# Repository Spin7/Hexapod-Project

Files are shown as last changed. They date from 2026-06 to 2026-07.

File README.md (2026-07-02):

# Hexapod Project

<p align="center">
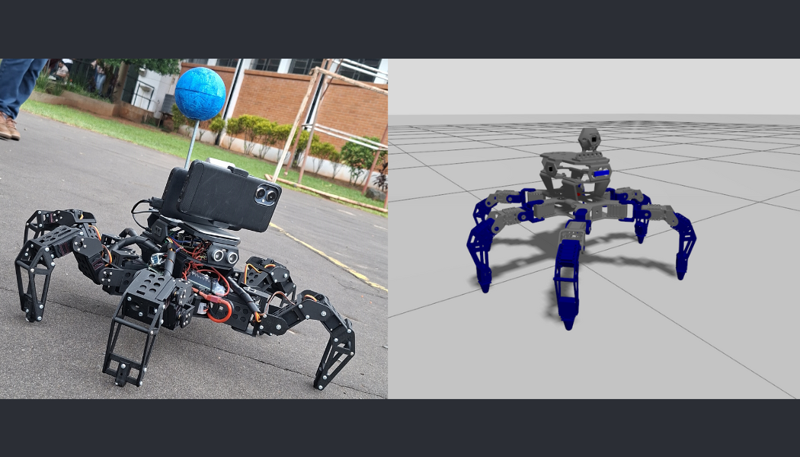
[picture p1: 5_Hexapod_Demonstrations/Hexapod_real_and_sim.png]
Hexapod — Real robot and Gazebo simulation
  
</p>

<p align="center">
  <em>Left: Physical hexapod robot in action · Right: Gazebo simulation counterpart</em>
</p>

<p align="center">
  
  
  
  
  
  
</p>

---

## Overview

This repository contains the complete development of a **6-legged autonomous robot (hexapod)** — from mechanical 3D design and embedded firmware, to a full ROS2 software stack running in both **Gazebo simulation** and on the **physical robot**.

The core philosophy is **dual-execution**: one shared intelligence layer drives two physical realities. The same high-level behaviors — autonomous navigation, vision-based following, swarm coordination, hand-gesture interaction — run identically on the simulator and the real hardware. The only difference is the actuation layer.

```
Behavior / Navigation / Social Logic
              ↓
      cmd_robot (std_msgs/String)
              ↓
  ┌───────────────────────────┐
  │ SIMULATION                │     │ REAL ROBOT                │
  │  gz_hexapod_low_level     │     │  dds_cmd_talker           │
  │    → joint trajectories   │     │    → serial → Arduino     │
  └───────────────────────────┘     └───────────────────────────┘
```

---

## Hardware Platform

| Component | Details |
|---|---|
| 🖥️ **PC** | ASUS TUF Gaming F15 — NVIDIA RTX 3060 · Ubuntu 24.04 LTS |
| 🍓 **Raspberry Pi** | Raspberry Pi 4 (4 GB RAM) · Ubuntu 24.04 LTS |
| 🔌 **Microcontroller** | Arduino Mega (18 servo motors — 3 DOF × 6 legs) |
| 📱 **Smartphone** | Google Pixel 7 (camera + IMU sensors via SensorServer) |
| 🦿 **Mechanics** | Custom 3D-printed chassis · SolidWorks design |
| 📡 **Sensors** | HC-SR04 ultrasonic · IMU · GPS (via smartphone) · IR proximity |

---

## Repository Structure

```
Hexapod Project/
├── 1_ROS2_Gazebo_Project/       # Full ROS2 package (simulation + real robot)
├── 2_Arduino_Code/              # Arduino Mega firmware (IK + gait + serial control)
├── 3_3D_Design/                 # SolidWorks assembly + printable STL files
├── 4_SensorServer_App/          # Android app APK for phone sensor streaming
├── 5_Hexapod_Demonstrations/    # Video demos and side-by-side images
└── 6_Multimedia/                # Photos and media assets
```

---

## Modules

### 1 — ROS2 Gazebo Project

> **Path:** [`1_ROS2_Gazebo_Project/`](1_ROS2_Gazebo_Project/)  
> **See:** [`1_ROS2_Gazebo_Project/README.md`](1_ROS2_Gazebo_Project/README.md)

The brain of the system. A single colcon package (`hexapod_pkg`) that runs on both the PC (simulation and high-level control) and the Raspberry Pi (hardware sensor reading).

**Key node groups:**

| Module | Role |
|---|---|
| `dds_nodes` | DDS bridge — PC ↔ Arduino serial communication |
| `navigation_nodes` | GPS-based autonomous navigation + obstacle avoidance |
| `image_recognition_nodes` | YOLO object detection + MediaPipe hand tracking |
| `localization_and_orientation_nodes` | GPS, IMU heading, dead-reckoning fusion |
| `sensors_interfaces_nodes` | Ultrasonic sensor processing |
| `social_robot_nodes` | Hand-gesture-based human–robot interaction |
| `auto_balance_nodes` | IMU-driven postural correction (roll/pitch) |
| `gazebo_nodes` | Simulation-specific low-level joint control |
| `read_sensors_nodes` | Hardware sensor readers (Raspberry Pi side) |
| `teleop_nodes` | Keyboard / manual override |

**Operation modes:**

| Mode | Description |
|---|---|
| 🎯 **Follower** | YOLO-based visual target tracking and pursuit |
| 🗺️ **Navigation to Target** | GPS + heading + obstacle avoidance autonomous travel |
| 🐝 **Swarm Follower** | Leader-following with simplified collective rules |
| 🖐️ **Social Robot** | Hand gesture recognition (ROCK / VICTORY / AL_PELO) → motion commands |
| 🕹️ **Teleop** | Direct keyboard control for debugging and calibration |

---

### 2 — Arduino Code

> **Path:** [`2_Arduino_Code/`](2_Arduino_Code/)

Arduino Mega firmware written in C++. Receives high-level movement commands over serial from the Raspberry Pi (via ROS2 DDS bridge) and translates them into real-time servo trajectories using **Inverse Kinematics (IK)**.

**Key features:**
- 18 servo motors controlled at **50 Hz** (20 ms frame time)
- 3 DOF per leg: **Coxa · Femur · Tibia** — lengths: 51 mm / 65 mm / 121 mm
- IK-based foot placement for forward, backward, lateral, and rotational gaits
- Battery voltage monitoring (12V analog input)
- Includes a PDF wiring and setup guide ([`Arduino_Instructions.pdf`](2_Arduino_Code/Arduino_Instructions.pdf))

---

### 3 — 3D Design

> **Path:** [`3_3D_Design/`](3_3D_Design/)

Full mechanical design created in **SolidWorks**. The assembly (`Ensamblaje.SLDASM`) covers the entire robot structure with all sub-components modeled and parametrized.

**Printable STL parts include:**

| Part | Description |
|---|---|
| `Body_Top_Plate.stl` / `Body_Bottom_Plate.stl` | Main chassis plates |
| `Body_Riser.stl` | Chassis elevation spacers |
| `Femur_Bracket.stl` / `Femur_Bracket_End_Cap.stl` | Mid-leg structural brackets |
| `Tibia_Bracket.stl` / `Tibia_Side_1.stl` / `Tibia_Side_2.stl` | Lower leg components |
| `Tibia_Foot_Bumper.stl` / `Tibia_Foot_Plate.stl` | Foot contact surface |
| `Servo_Mount.stl` / `Servo_Bearing_Center.stl` | Servo attachment fixtures |
| `Wire_Guide.stl` | Cable management |
| `Receiver_Holder.stl` / `SBEC_Holder.stl` | Electronics holders |
| `Soporte/` | Mounting brackets for Raspberry Pi 5 and Pi Camera |

Additional sub-assemblies include custom mounts for the **HC-SR04** ultrasonic sensors and the **JS40F** servo joints. A full parts list is available at [`stl files/Robot/Parts-List.pdf`](3_3D_Design/Hexapod%203D%20model/stl%20files/Robot/Parts-List.pdf).

---

### 4 — SensorServer App

> **Path:** [`4_SensorServer_App/`](4_SensorServer_App/)  
> **GitHub:** [github.com/UmerCodez/SensorServer](https://github.com/UmerCodez/SensorServer)

An Android application that streams all smartphone sensors (GPS, accelerometer, gyroscope, magnetometer) over **WebSocket** to the ROS2 network. This turns a regular smartphone into a powerful sensor hub for the hexapod, providing:

- **GPS** — global position for autonomous navigation
- **IMU** — accelerometer + gyroscope + magnetometer for heading estimation
- **Camera** — phone camera streamed via **IriunWebCam** to the PC

The APK is included in this folder for direct installation.

---

### 5 — Hexapod Demonstrations

> **Path:** [`5_Hexapod_Demonstrations/`](5_Hexapod_Demonstrations/)  
> **See:** [`5_Hexapod_Demonstrations/README.md`](5_Hexapod_Demonstrations/README.md)

Video recordings of all operation modes on both the real robot and the simulation. Organized into two sub-folders:

<p align="center">
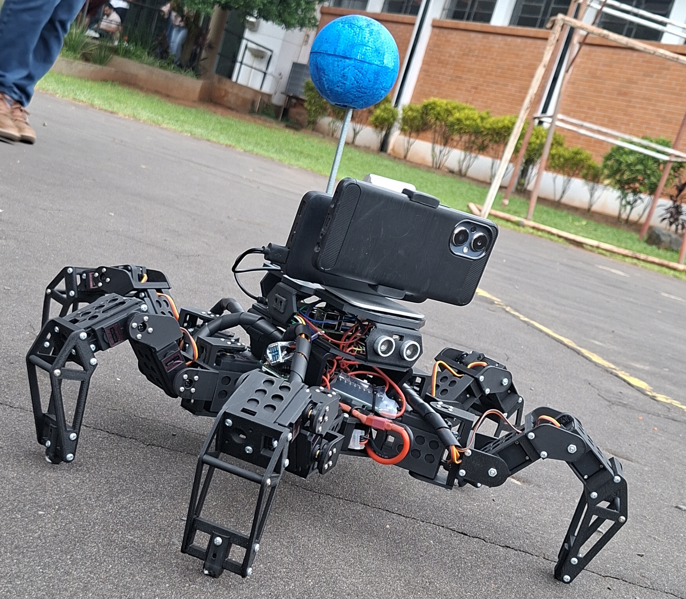
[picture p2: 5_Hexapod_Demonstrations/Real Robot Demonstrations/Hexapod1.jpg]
Hexapod Robot
  
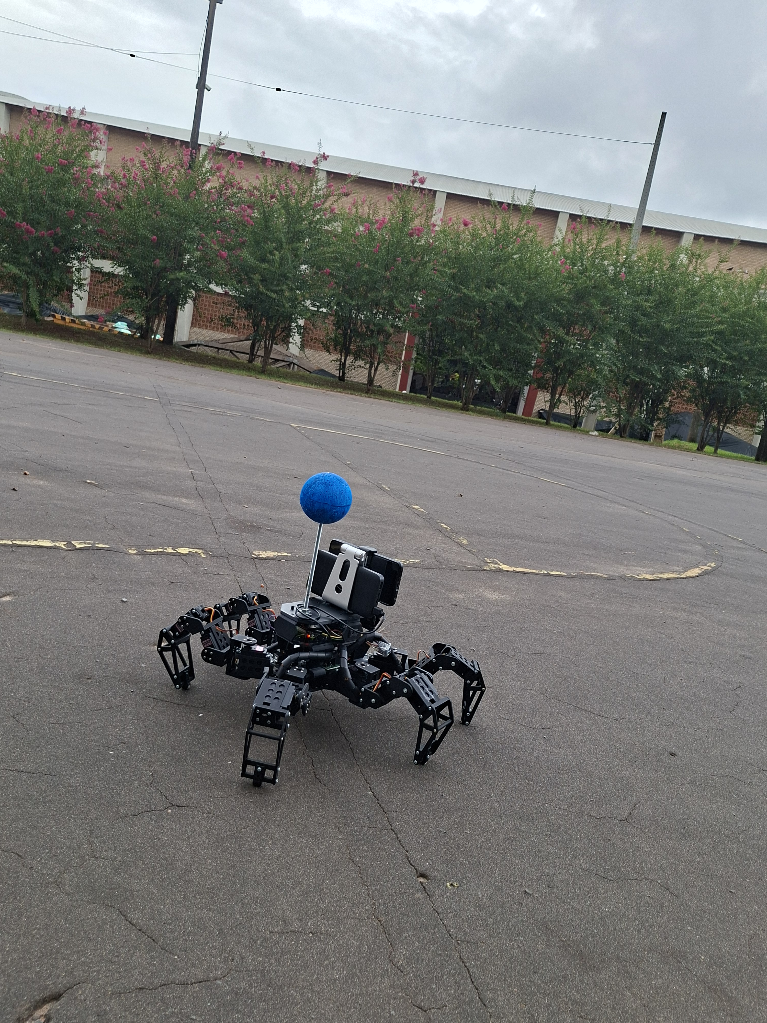
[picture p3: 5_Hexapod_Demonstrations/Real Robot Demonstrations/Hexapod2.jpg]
Hexapod Robot outdoor
  
</p>
<p align="center">
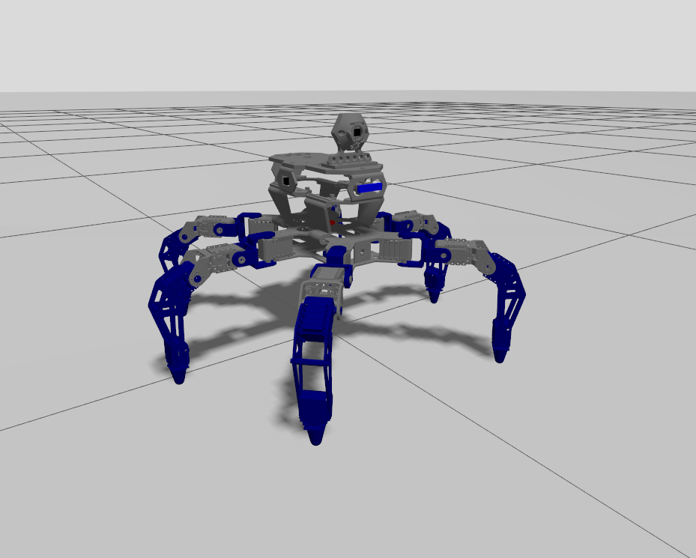
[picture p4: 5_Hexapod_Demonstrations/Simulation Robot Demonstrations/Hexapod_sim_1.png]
Gazebo Simulation
  
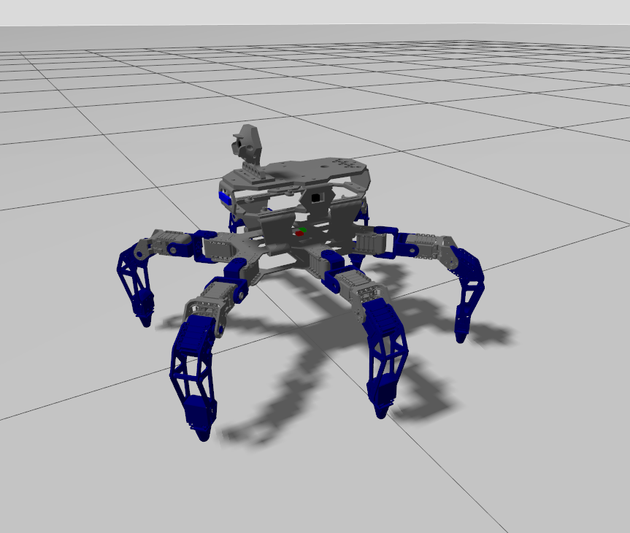
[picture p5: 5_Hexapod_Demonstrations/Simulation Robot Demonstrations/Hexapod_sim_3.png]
Gazebo Simulation
  
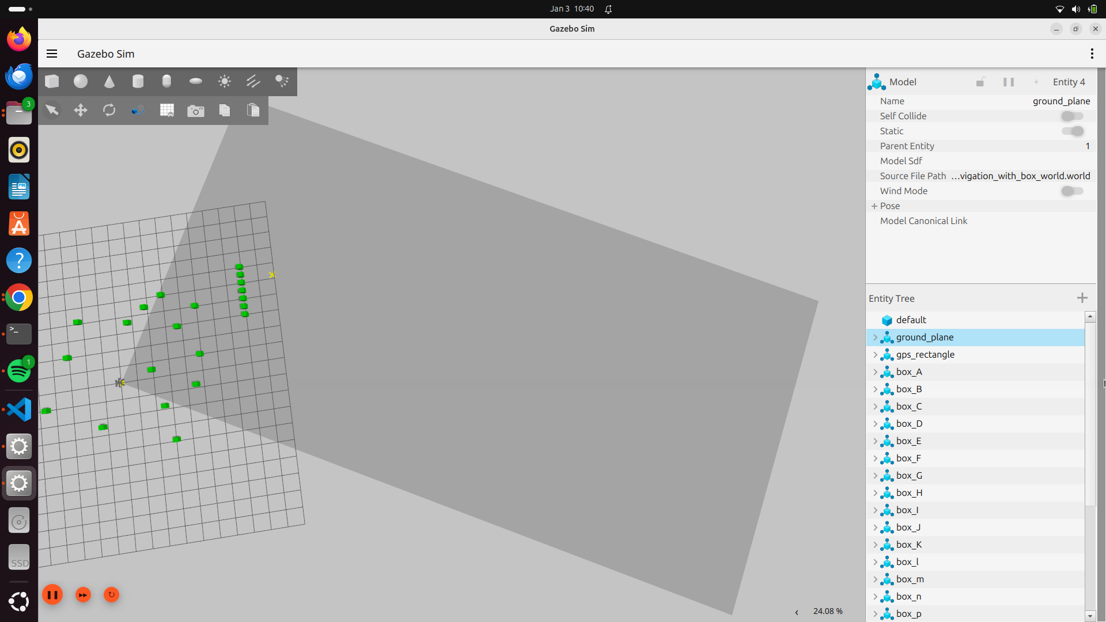
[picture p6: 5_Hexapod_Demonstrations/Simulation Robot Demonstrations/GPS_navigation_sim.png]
GPS Navigation
  
</p>

**Real Robot Demonstrations (9 videos):**

| # | Video | Description |
|---|---|---|
| 1 | `1_Hexapod_dds_comunication_launch.mp4` | DDS bridge startup and Arduino handshake |
| 2 | `2_Hexapod_teleop_node.mp4` | Manual keyboard teleoperation |
| 3 | `3_Hexapod_autobalance_node.mp4` | Auto-balance / IMU stabilization |
| 4 | `4_Hexapod_compute_sensors_launch.mp4` | Sensor processing pipeline |
| 5 | `5_Hexapod_follower_launch.mp4` | Vision-based follower mode |
| 6 | `6_Hexapod_swarm_follower_launch.mp4` | Swarm follower behavior |
| 7 | `7_Hexapod_gps_navigation_launch.mp4` | GPS navigation setup |
| 8 | `8_Hexapod_follower_demonstration.mp4` | Full follower demo in real environment |
| 9 | `9_Hexapod_gps_navigation_demonstration.mp4` | Full autonomous GPS navigation demo |

**Simulation Demonstrations (7 videos):**

| # | Video | Description |
|---|---|---|
| 1 | `1_Hexapod_gazebo_launch.mp4` | Gazebo world startup and robot spawn |
| 2 | `2_Hexapod_teleop_node_sim.mp4` | Keyboard teleoperation in simulation |
| 3 | `3_Hexapod_sensors_compute_sim.mp4` | Sensor compute pipeline in simulation |
| 4 | `4_Hexapod_follower_sim.mp4` | Follower mode in Gazebo |
| 5 | `5_Hexapod_swarm_follower_sim.mp4` | Swarm follower in Gazebo |
| 6 | `6_Hexapod_gps_navigation_sim.mp4` | Full GPS navigation in simulation |
| 7 | `7_Hexapod_social_robot_launch_sim.mp4` | Hand gesture control in Gazebo |

---

### 6 — Multimedia

> **Path:** [`6_Multimedia/`](6_Multimedia/)

Raw photos and media assets of the physical robot from construction and testing sessions.

---

## Quick Start

### Prerequisites

- Ubuntu 22.04 or 24.04
- ROS2 Humble / Jazzy (recommended: Jazzy on Ubuntu 24.04)
- Gazebo Harmonic (`ros-jazzy-ros-gz`)
- Python 3 with `torch`, `ultralytics`, `opencv-python`
- Arduino IDE (for firmware upload)
- SolidWorks (for 3D model editing — STL files work without it)

### Clone & Build

```bash
# Create workspace
mkdir -p ~/ros2_hexapod_ws/src
cd ~/ros2_hexapod_ws/src

# Clone repository
git clone https://github.com/Spin7/Hexapod-Project.git

# Copy ROS2 package into workspace
cp -r Hexapod-Project/1_ROS2_Gazebo_Project/hexapod_pkg .

# Build
cd ~/ros2_hexapod_ws
colcon build --symlink-install
source install/setup.bash
```

### Run (Simulation)

```bash
# Terminal 1 — start Gazebo
ros2 launch hexapod_pkg gazebo_hexapod_sim.launch.py

# Terminal 2 — sensor processing
ros2 launch hexapod_pkg sensors_compute_sim.launch.py

# Terminal 3 — pick a mode
ros2 launch hexapod_pkg follower_sim.launch.py               # Vision follower
ros2 launch hexapod_pkg navigation_to_target_sim.launch.py  # GPS navigation
ros2 launch hexapod_pkg social_robot_sim.launch.py          # Hand gestures
ros2 launch hexapod_pkg swarm_follower_sim.launch.py        # Swarm
```

> See [`1_ROS2_Gazebo_Project/README.md`](1_ROS2_Gazebo_Project/README.md) for the full setup guide including real robot deployment.

---

## Architecture Diagram

```
┌──────────────────────────────────────────────────────────────────┐
│                         PC (Ubuntu 24.04)                        │
│                                                                  │
│  ┌─────────────────────────────────────────────────────────┐    │
│  │                    ROS2 Jazzy                           │    │
│  │                                                         │    │
│  │  ┌──────────┐  ┌──────────┐  ┌──────────┐  ┌────────┐ │    │
│  │  │ YOLO /   │  │   GPS    │  │ Obstacle │  │Gesture │ │    │
│  │  │ Camera   │  │ Navigation│  │ Avoidance│  │  HRI   │ │    │
│  │  └────┬─────┘  └────┬─────┘  └────┬─────┘  └───┬────┘ │    │
│  │       └─────────────┴─────────────┴─────────────┘      │    │
│  │                        cmd_robot                        │    │
│  │                            │                           │    │
│  │          ┌─────────────────┴─────────────────┐         │    │
│  │          │ SIMULATION          REAL ROBOT     │         │    │
│  │          │  Gazebo joints      DDS → Serial   │         │    │
│  │          └─────────────────────┬─────────────┘         │    │
│  └────────────────────────────────┼────────────────────────┘    │
└───────────────────────────────────┼──────────────────────────────┘
                                    │ Serial / USB
                         ┌──────────┴──────────┐
                         │   Raspberry Pi 4    │
                         │   (ROS2 sensors)    │
                         └──────────┬──────────┘
                                    │ Serial
                         ┌──────────┴──────────┐
                         │   Arduino Mega      │
                         │  18 servos — IK     │
                         └─────────────────────┘
                                    │
                         ┌──────────┴──────────┐
                         │  Smartphone (Pixel) │
                         │  GPS · IMU · Camera │
                         └─────────────────────┘
```

---

## License

This project is open source. Feel free to use, fork, and build on it.  
If you use this work in your own project, a mention or link back is appreciated.

---

<p align="center">
  Built with ROS2 · Gazebo · Arduino · SolidWorks · YOLO · MediaPipe
</p>

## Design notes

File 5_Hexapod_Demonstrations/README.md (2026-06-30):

# 🎬 Hexapod Demonstrations

<p align="center">
  Hexapod — Real robot and Gazebo simulation
</p>

<p align="center">
  <em>Left: Physical robot in the real world · Right: Gazebo simulation counterpart</em>
</p>

Video demonstrations of the hexapod robot operating in both **Gazebo simulation** and on the **real hardware**. Each subfolder contains a detailed video index with YouTube thumbnails, descriptions, and launch commands.

---

## 🎮 [Simulation Robot Demonstrations](Simulation%20Robot%20Demonstrations/README.md) — 7 videos

All behaviors running inside **Gazebo Harmonic + ROS2 Jazzy**. No hardware required.

| # | Mode |
|---|---|
| 1 | Gazebo World Launch |
| 2 | Teleoperation |
| 3 | Sensor Computation Layer |
| 4 | Vision-Based Follower (YOLO) |
| 5 | Swarm Follower |
| 6 | Autonomous GPS Navigation |
| 7 | Social Robot — Hand Gestures |

---

## 🤖 [Real Robot Demonstrations](Real%20Robot%20Demonstrations/README.md) — 9 videos

The same behaviors on physical hardware: Raspberry Pi 4 + Arduino Mega + 18 servo motors.

| # | Mode |
|---|---|
| 1 | DDS Communication Launch |
| 2 | Teleoperation |
| 3 | Auto-Balance Controller |
| 4 | Sensor Computation Layer |
| 5 | Vision-Based Follower Launch |
| 6 | Swarm Follower Launch |
| 7 | GPS Navigation Launch |
| 8 | Follower — Full Demo |
| 9 | GPS Navigation — Full Demo |

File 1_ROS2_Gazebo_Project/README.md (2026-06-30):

# Hexapod Project — ROS2 Package
<p align="center">
  The hexapod robot
</p>

> **Part of the [Hexapod Project](https://github.com/Spin7/Hexapod-Project)**  
> This folder contains the full ROS2 package (`hexapod_pkg`) for both **Gazebo simulation** and **real robot** operation.

---

## Reference Setup

| Component | Hardware | OS |
|---|---|---|
| 🖥️ **PC** | ASUS TUF Gaming F15 (NVIDIA RTX 3060) | Ubuntu 24.04 LTS |
| 🍓 **Raspberry Pi** | Raspberry Pi 4 — 4 GB RAM | Ubuntu 24.04 LTS |
| 📱 **Smartphone** | Google Pixel 7 | Android (sensors + camera) |
| 🔌 **Microcontroller** | Arduino Mega | — |

> **Note (YOLO & GPU):** A dedicated GPU is **strongly recommended** for real-time YOLO-based vision. Without one, detection will still work but with limited performance.

---

## 1. PC Installation

### 1.1. Install ROS2

Choose the version that matches your Ubuntu distribution:

| Ubuntu | ROS2 Distribution |
|---|---|
| 22.04 | [ROS2 Humble](https://docs.ros.org/en/humble/Installation/Ubuntu-Install-Debians.html) |
| 24.04 | [ROS2 Jazzy](https://docs.ros.org/en/jazzy/Installation/Ubuntu-Install-Debians.html) *(Recommended)* |
| 24.04 | [ROS2 Rolling](https://docs.ros.org/en/rolling/Installation/Ubuntu-Install-Debians.html) |

---

### 1.2. Install build tools

```bash
sudo apt update
sudo apt install python3-colcon-common-extensions
```

---

### 1.3. Source ROS2 and colcon permanently

```bash
echo "source /opt/ros/jazzy/setup.bash" >> ~/.bashrc
echo "source /usr/share/colcon_cd/function/colcon_cd.sh" >> ~/.bashrc
source ~/.bashrc
```

> **OBS:** Replace `jazzy` with your distribution (`humble`, `rolling`, etc.)

---

### 1.4. Install Gazebo (Harmonic) and the ROS2–Gazebo bridge

```bash
sudo apt install ros-jazzy-ros-gz
```

> **OBS:** Replace `jazzy` with your ROS2 distribution. This installs `ros_gz_sim`, `ros_gz_bridge`, and all related packages needed for simulation.

---

### 1.5. Install IriunWebCam (phone camera support)

```bash
wget https://iriun.gitlab.io/iriunwebcam-2.9.deb
sudo apt install ./iriunwebcam-2.9.deb
sudo apt --fix-broken install
```

---

### 1.6. Check GPU / CUDA support *(skip if no GPU)*

```bash
nvidia-smi
```

Expected output when GPU is ready:

```
+-----------------------------------------------------------------------------+
| NVIDIA-SMI 510.79.02    Driver Version: 510.79.02    CUDA Version: 11.6     |
|-------------------------------+----------------------+----------------------+
| GPU  Name        Persistence-M| Bus-Id        Disp.A | Volatile Uncorr. ECC |
...
+-----------------------------------------------------------------------------+
```

If the command fails, install NVIDIA drivers via Ubuntu autodetect:

```bash
sudo apt update
sudo apt install ubuntu-drivers-common
sudo ubuntu-drivers autoinstall
sudo reboot
```

---

### 1.7. Create a Python virtual environment for YOLO

```bash
python3 -m venv ~/.venvs/yolo
source ~/.venvs/yolo/bin/activate
```

> **OBS:** Always activate this environment in a **separate terminal** from the one running the ROS2 nodes.

---

### 1.8. Install YOLO dependencies inside the virtual environment

```bash
pip install torch torchvision torchaudio
pip install ultralytics
pip install opencv-python
```

---

### 1.9. Install OpenCV system-wide (for ROS2 nodes)

```bash
sudo apt install python3-opencv
```

---

### 1.10. Create the ROS2 workspace

```bash
mkdir -p ~/ros2_hexapod_ws/src
cd ~/ros2_hexapod_ws/src
```

---

### 1.11. Clone the repository

```bash
git clone https://github.com/Spin7/Hexapod-Project.git
```

The ROS2 package lives inside the cloned repo at:

```
Hexapod-Project/
└── 1_ROS2_Gazebo_Project/
    └── hexapod_pkg/      ← the colcon package
```

Copy only the package into the workspace `src/` so colcon can find it:

```bash
cp -r ~/ros2_hexapod_ws/src/Hexapod-Project/1_ROS2_Gazebo_Project/hexapod_pkg \
      ~/ros2_hexapod_ws/src/
```

---

### 1.12. Build the workspace

```bash
cd ~/ros2_hexapod_ws
colcon build --symlink-install
```

---

### 1.13. Source the workspace permanently

```bash
echo "source ~/ros2_hexapod_ws/install/setup.bash" >> ~/.bashrc
source ~/.bashrc
```

---

## 2. Raspberry Pi Installation

### 2.1. Install ROS2

Same as PC — choose based on your Ubuntu version (see [step 1.1](#11-install-ros2)).

---

### 2.2. Install build tools

```bash
sudo apt update
sudo apt install python3-colcon-common-extensions
```

---

### 2.3. Source ROS2 and colcon permanently

```bash
echo "source /opt/ros/jazzy/setup.bash" >> ~/.bashrc
echo "source /usr/share/colcon_cd/function/colcon_cd.sh" >> ~/.bashrc
source ~/.bashrc
```

> **OBS:** Replace `jazzy` with your ROS2 distribution.

---

### 2.4. Install hardware interface dependencies

```bash
sudo apt update
sudo apt install python3-smbus
sudo apt install python3-smbus2
sudo apt install python3-rpi.gpio
sudo apt install python3-serial
sudo apt install python3-opencv
```

---

### 2.5. Create the ROS2 workspace

```bash
mkdir -p ~/ros2_hexapod_ws/src
cd ~/ros2_hexapod_ws/src
```

---

### 2.6. Clone the repository

```bash
git clone https://github.com/Spin7/Hexapod-Project.git
```

Copy the package into the workspace `src/`:

```bash
cp -r ~/ros2_hexapod_ws/src/Hexapod-Project/1_ROS2_Gazebo_Project/hexapod_pkg \
      ~/ros2_hexapod_ws/src/
```

---

### 2.7. Build the workspace

```bash
cd ~/ros2_hexapod_ws
colcon build --symlink-install
```

---

### 2.8. Source the workspace permanently

```bash
echo "source ~/ros2_hexapod_ws/install/setup.bash" >> ~/.bashrc
source ~/.bashrc
```

---

## 3. Running the Package

The system is launched in layers. Each mode requires specific launches to be started **in order**.

### 3.1. Simulation (PC only)

```bash
# Terminal 1 — MANDATORY: start Gazebo + spawn robot
ros2 launch hexapod_pkg gazebo_hexapod_sim.launch.py

# Terminal 2 — optional (required for navigation modes)
ros2 launch hexapod_pkg sensors_compute_sim.launch.py

# Terminal 3 — pick ONE operation mode:
ros2 launch hexapod_pkg navigation_to_target_sim.launch.py  # Autonomous navigation
ros2 launch hexapod_pkg follower_sim.launch.py              # Vision-based follower
ros2 launch hexapod_pkg swarm_follower_sim.launch.py        # Swarm follower
ros2 launch hexapod_pkg social_robot_sim.launch.py          # Hand gesture control
```

### 3.2. Real Robot (PC + Raspberry Pi)

**On the Raspberry Pi:**
```bash
# Terminal 1 — MANDATORY: read hardware sensors
ros2 launch hexapod_pkg read_sensors_rasberrypi.launch.py
```

**On the PC:**
```bash
# Terminal 1 — MANDATORY: DDS bridge to Arduino
ros2 launch hexapod_pkg dds_comunication.launch.py

# Terminal 2 — optional (required for navigation modes)
ros2 launch hexapod_pkg sensors_compute_real.launch.py

# Terminal 3 — pick ONE operation mode:
ros2 launch hexapod_pkg navigation_to_target_real.launch.py # Autonomous navigation
ros2 launch hexapod_pkg follower_real.launch.py             # Vision-based follower
ros2 launch hexapod_pkg swarm_follower_real.launch.py       # Swarm follower
ros2 launch hexapod_pkg social_robot_real.launch.py         # Hand gesture control
```

---

## 4. Package Structure

```
hexapod_pkg/
├── config/                         # ROS2 parameters and bridge config (gz_bridge.yaml)
├── description_hexapod/            # URDF/XACRO robot model
├── hexapod_pkg/                    # Python source nodes
│   ├── dds_nodes/                  # DDS communication (PC ↔ Arduino)
│   ├── gazebo_nodes/               # Gazebo-specific control and IR emulation
│   ├── localization_and_orientation_nodes/  # GPS, heading, dead-reckoning
│   ├── sensors_interfaces_nodes/   # Ultrasonic sensor processing
│   ├── master_nodes/               # System health monitor
│   ├── camera_nodes/               # WebCam node
│   ├── image_recognition_nodes/    # YOLO and classic vision detectors
│   ├── teleop_nodes/               # Keyboard / manual control
│   ├── navigation_nodes/           # Autonomous navigation planners
│   ├── social_robot_nodes/         # Gesture-based HRI
│   ├── read_sensors_nodes/         # Hardware sensor readers (Raspberry Pi)
│   └── auto_balance_nodes/         # Balance controller
├── launch/                         # Real robot launches (PC side)
├── launch_pi/                      # Real robot launches (Raspberry Pi side)
├── launch_sim/                     # Simulation launches
├── meshes/                         # 3D mesh files
├── models/                         # Gazebo model definitions
├── worlds/                         # Gazebo world files
├── CMakeLists.txt
└── package.xml
```

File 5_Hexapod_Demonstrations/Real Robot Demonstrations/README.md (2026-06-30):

# Real Robot Demonstrations

<p align="center">
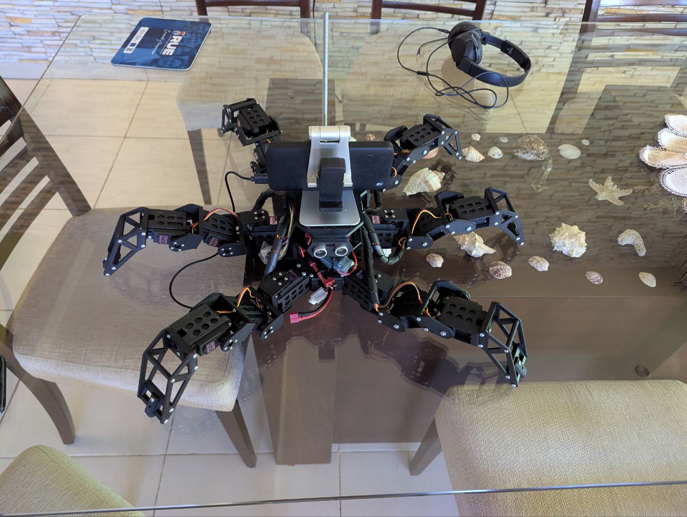
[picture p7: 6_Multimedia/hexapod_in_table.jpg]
Hexapod physical robot
  
</p>

> **Part of the [Hexapod Project](https://github.com/Spin7/Hexapod-Project)**  
> 9 videos of the hexapod robot operating on **real hardware**: Raspberry Pi 4 + Arduino Mega + 18 servo motors. Real sensors, real noise, real world.

🎬 **YouTube Playlist:** [Hexapod Project — Real Robot (Raspberry Pi + Arduino)](#-add-playlist-link-here)

---

## 📸 Robot Photos

<p align="center">
  Hexapod Robot — front view
  Hexapod Robot — outdoor
</p>
<p align="center">
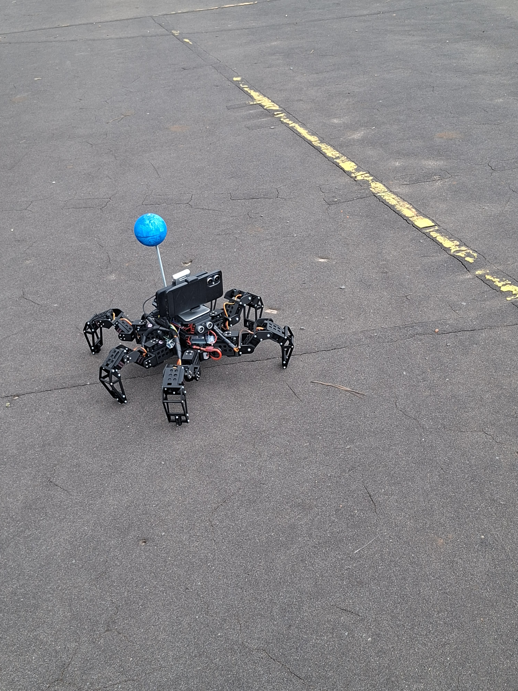
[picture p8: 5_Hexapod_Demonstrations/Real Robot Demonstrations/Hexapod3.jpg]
Hexapod Robot — detail
  
</p>

---

## 🔧 Hardware Stack

| Component | Details |
|---|---|
| 🖥️ **PC** | ASUS TUF Gaming F15 — NVIDIA RTX 3060 · Ubuntu 24.04 |
| 🍓 **Raspberry Pi** | Pi 4 (4 GB) · Ubuntu 24.04 — sensor reading + ROS2 |
| 🔌 **Arduino Mega** | 18 servos (3 DOF × 6 legs) · IK firmware · 50 Hz |
| 📱 **Google Pixel 7** | GPS + IMU (SensorServer) + camera (IriunWebCam) |
| 📡 **Sensors** | HC-SR04 ultrasonic · BerryIMU · IR proximity |

---

## 🎬 Video Index

> **How to watch:** Click the thumbnail or title to open the video on YouTube.

---

### Part 1 — DDS Communication Launch

**File:** `1_Hexapod_dds_comunication_launch.mp4`  
**Title:** *Hexapod Project - Real Robot Part 1 (DDS Communication Launch)*

<p align="center">
  <a href="https://youtu.be/VLH7wAWyUxs">
    ▶ Watch: DDS Communication Launch
  </a>
</p>
<p align="center"><em>▶ Click to watch on YouTube</em></p>

**Description:**  
The first step to operating the real hexapod robot is establishing the **DDS communication bridge** between the PC (running ROS2) and the robot (Raspberry Pi + Arduino Mega).

This launch starts:
- 📻 DDS fast listener — IMU, ultrasonic, IR, camera data
- 📡 DDS reliable listener — GPS data
- 📢 DDS command talker — `cmd_robot` → serial → Arduino

Without this layer, the real robot is completely **blind and deaf**.

**Stack:** `ROS2 Jazzy` · `Raspberry Pi 4` · `Arduino Mega` · `DDS / Fast-DDS`

**Launch commands:**
```bash
# On Raspberry Pi:
ros2 launch hexapod_pkg read_sensors_rasberrypi.launch.py

# On PC:
ros2 launch hexapod_pkg dds_comunication.launch.py
```

---

### Part 2 — Teleoperation

**File:** `2_Hexapod_teleop_node.mp4`  
**Title:** *Hexapod Project - Real Robot Part 2 (Teleoperation)*

<p align="center">
  <a href="https://youtu.be/U2Dk3tRs2tY">
    ▶ Watch: Teleoperation
  </a>
</p>
<p align="center"><em>▶ Click to watch on YouTube</em></p>

**Description:**  
With the DDS communication bridge active, in this video I take direct manual control of the physical hexapod robot using **keyboard-based teleoperation**.

Each keypress travels through the full stack:
```
PC → DDS talker → serial protocol → Arduino Mega → servo motors
```

You can see the real hexapod walking, turning, and responding in real time to keyboard inputs.

**Stack:** `ROS2 Jazzy` · `Raspberry Pi 4` · `Arduino Mega` · `teleop node`

**Launch command:**
```bash
ros2 launch hexapod_pkg dds_comunication.launch.py
# Then in a new terminal:
ros2 run hexapod_pkg teleop_hexapod
```

---

### Part 3 — Auto-Balance Controller

**File:** `3_Hexapod_autobalance_node.mp4`  
**Title:** *Hexapod Project - Real Robot Part 3 (Auto-Balance Controller)*

<p align="center">
  <a href="https://youtu.be/IZbR-sUqEJs">
    ▶ Watch: Auto-Balance Controller
  </a>
</p>
<p align="center"><em>▶ Click to watch on YouTube</em></p>

**Description:**  
The **balance controller** adds a postural correction layer that runs between navigation commands and raw servo actuation.

Using IMU data and estimated body orientation, the controller continuously compensates for:
- ⛰️ Uneven terrain
- ⚙️ Servo delays and mechanical asymmetry
- 🔄 Roll and pitch disturbances

In this video you can see the real hexapod actively stabilizing its body while moving — improving gait robustness on real surfaces.

**Stack:** `ROS2 Jazzy` · `IMU` · `BerryIMU` · `Raspberry Pi 4` · `Arduino Mega`

---

### Part 4 — Sensor Computation Layer

**File:** `4_Hexapod_compute_sensors_launch.mp4`  
**Title:** *Hexapod Project - Real Robot Part 4 (Sensor Computation Layer)*

<p align="center">
  <a href="https://youtu.be/g3vVCbwPKyo">
    ▶ Watch: Sensor Computation Layer
  </a>
</p>
<p align="center"><em>▶ Click to watch on YouTube</em></p>

**Description:**  
Before running any autonomous behavior on the real robot, the sensor computation stack must be active. This launch processes data from real hardware sensors into navigation-ready signals:

- 📍 GPS → local XY coordinates
- 🧭 Phone magnetometer → orientation angle
- 📐 Dead-reckoning position estimate
- 📡 Ultrasonic → obstacle distances in meters
- 🔎 Master monitor for system health

This is the **real-world equivalent** of the simulation sensor layer.

**Stack:** `ROS2 Jazzy` · `GPS` · `BerryIMU` · `Ultrasonic` · `Google Pixel 7`

**Launch command:**
```bash
ros2 launch hexapod_pkg dds_comunication.launch.py
ros2 launch hexapod_pkg sensors_compute_real.launch.py
```

---

### Part 5 — Vision-Based Follower Launch

**File:** `5_Hexapod_follower_launch.mp4`  
**Title:** *Hexapod Project - Real Robot Part 5 (Vision-Based Follower Launch)*

<p align="center">
  <a href="https://youtu.be/iJXCLiiwyK0">
    ▶ Watch: Vision-Based Follower Launch
  </a>
</p>
<p align="center"><em>▶ Click to watch on YouTube</em></p>

**Description:**  
Launching the **follower mode** on the real physical hexapod robot. The robot uses a camera (phone / USB webcam) and a YOLO model to detect a target object and follow it in real time.

This video shows the launch sequence and system initialization — camera node, YOLO detector, and the follower navigation node all coming online together.

**Stack:** `ROS2 Jazzy` · `YOLO (Ultralytics)` · `OpenCV` · `Google Pixel 7`

**Launch command:**
```bash
ros2 launch hexapod_pkg dds_comunication.launch.py
ros2 launch hexapod_pkg sensors_compute_real.launch.py
ros2 launch hexapod_pkg follower_real.launch.py
```

---

### Part 6 — Swarm Follower Launch

**File:** `6_Hexapod_swarm_follower_launch.mp4`  
**Title:** *Hexapod Project - Real Robot Part 6 (Swarm Follower Launch)*

<p align="center">
  <a href="https://youtu.be/b_1az8GlGhw">
    ▶ Watch: Swarm Follower Launch
  </a>
</p>
<p align="center"><em>▶ Click to watch on YouTube</em></p>

**Description:**  
Launching the **swarm follower mode** on the real hexapod. This behavior is designed for multi-robot coordination, where each unit follows a leader using vision and obstacle-aware navigation.

In single-robot operation (shown here), the swarm logic acts as a compact reactive follower. This video covers the full launch sequence including YOLO vision and the swarm navigation node initialization.

**Stack:** `ROS2 Jazzy` · `YOLO` · `Raspberry Pi 4` · `Arduino Mega`

**Launch command:**
```bash
ros2 launch hexapod_pkg dds_comunication.launch.py
ros2 launch hexapod_pkg sensors_compute_real.launch.py
ros2 launch hexapod_pkg swarm_follower_real.launch.py
```

---

### Part 7 — GPS Navigation Launch

**File:** `7_Hexapod_gps_navigation_launch.mp4`  
**Title:** *Hexapod Project - Real Robot Part 7 (GPS Navigation Launch)*

<p align="center">
  <a href="https://youtu.be/4EwRCGkaTQo">
    ▶ Watch: GPS Navigation Launch
  </a>
</p>
<p align="center"><em>▶ Click to watch on YouTube</em></p>

**Description:**  
Launching the full **autonomous GPS navigation stack** on the real hexapod robot. This video shows the complete system initialization sequence:

- 🔗 DDS communication bridge
- 📡 Real sensor computation (GPS, IMU, ultrasonic)
- 👁️ YOLO cube detector
- 🗺️ Autonomous navigation planner with obstacle avoidance

All nodes coming online on real hardware before the robot begins its mission.

**Stack:** `ROS2 Jazzy` · `GPS` · `YOLO` · `Ultrasonic` · `Raspberry Pi 4` · `Arduino`

**Launch command:**
```bash
ros2 launch hexapod_pkg dds_comunication.launch.py
ros2 launch hexapod_pkg sensors_compute_real.launch.py
ros2 launch hexapod_pkg navigation_to_target_real.launch.py
```

---

### Part 8 — Follower Full Demo

**File:** `8_Hexapod_follower_demonstration.mp4`  
**Title:** *Hexapod Project - Real Robot Part 8 (Follower Full Demo)*

<p align="center">
  <a href="https://youtu.be/CMZotYHFU5w">
    ▶ Watch: Follower Full Demo
  </a>
</p>
<p align="center"><em>▶ Click to watch on YouTube</em></p>

**Description:**  
**Full demonstration** of the vision-based follower behavior running on the real physical hexapod robot.

The robot detects a moving target using YOLO and autonomously follows it through real-world space — dealing with:
- Real camera latency
- Physical motion instability
- Lighting and environment variation
- Obstacle avoidance on real terrain

A complete end-to-end test of the **perception → navigation pipeline** on real hardware.

**Stack:** `ROS2 Jazzy` · `YOLO` · `OpenCV` · `Raspberry Pi 4` · `Arduino Mega`

---

### Part 9 — GPS Navigation Full Demo

**File:** `9_Hexapod_gps_navigation_demonstration.mp4`  
**Title:** *Hexapod Project - Real Robot Part 9 (GPS Navigation Full Demo)*

<p align="center">
  <a href="https://youtu.be/iqLUGNQwuDo">
    ▶ Watch: GPS Navigation Full Demo
  </a>
</p>
<p align="center"><em>▶ Click to watch on YouTube</em></p>

**Description:**  
The **crown jewel** of the real robot series — a full end-to-end autonomous GPS navigation demonstration with obstacle avoidance.

The hexapod:
1. 🛰️ Receives a GPS target coordinate
2. 📍 Estimates its own position using GPS + dead-reckoning
3. 🧭 Computes heading from the phone's magnetometer
4. 📡 Detects obstacles with ultrasonic sensors
5. 👁️ Detects the target cube using YOLO
6. 🔄 Plans and replans motion commands continuously
7. 🏁 Reaches the goal while avoiding everything in its path

All of this running on real hardware, in the real world.

**Stack:** `ROS2 Jazzy` · `GPS` · `YOLO` · `IMU` · `Ultrasonic` · `Raspberry Pi 4` · `Arduino Mega`

---

## Common Setup (All Real Robot Modes)

```bash
# ─── On Raspberry Pi ───────────────────────────────────────
source /opt/ros/jazzy/setup.bash
source ~/ros2_hexapod_ws/install/setup.bash
ros2 launch hexapod_pkg read_sensors_rasberrypi.launch.py

# ─── On PC ─────────────────────────────────────────────────
source /opt/ros/jazzy/setup.bash
source ~/ros2_hexapod_ws/install/setup.bash

# (Modes with YOLO) Activate Python venv in a separate terminal
source ~/.venvs/yolo/bin/activate

# Start DDS bridge (ALWAYS first on PC)
ros2 launch hexapod_pkg dds_comunication.launch.py
```

> 📦 Full setup instructions: [1_ROS2_Gazebo_Project/README.md](../../1_ROS2_Gazebo_Project/README.md)

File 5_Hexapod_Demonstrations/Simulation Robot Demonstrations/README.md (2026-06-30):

# 🎮 Simulation Robot Demonstrations

<p align="center">
  Hexapod Simulation in Gazebo
</p>

> **Part of the [Hexapod Project](https://github.com/Spin7/Hexapod-Project)**  
> 7 videos showing the hexapod robot operating inside **Gazebo Harmonic** with **ROS2 Jazzy** — no physical hardware required.

🎬 **YouTube Playlist:** [Hexapod Project — Simulation (Gazebo + ROS2)](#-add-playlist-link-here)

---

## 📸 Simulation Screenshots

<p align="center">
  Hexapod in Gazebo — view 1
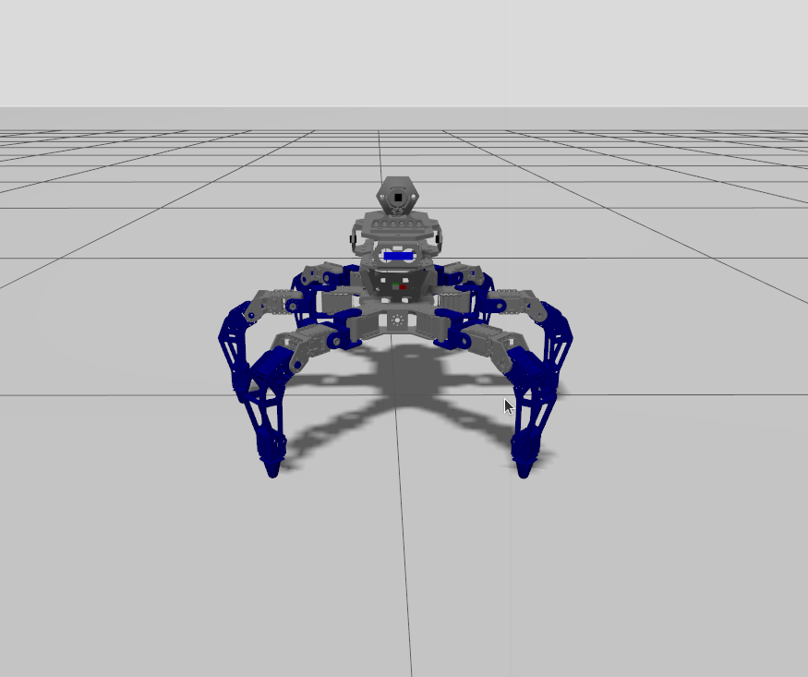
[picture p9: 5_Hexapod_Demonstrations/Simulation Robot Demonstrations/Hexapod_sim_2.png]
Hexapod in Gazebo — view 2
  
  Hexapod in Gazebo — view 3
</p>
<p align="center">
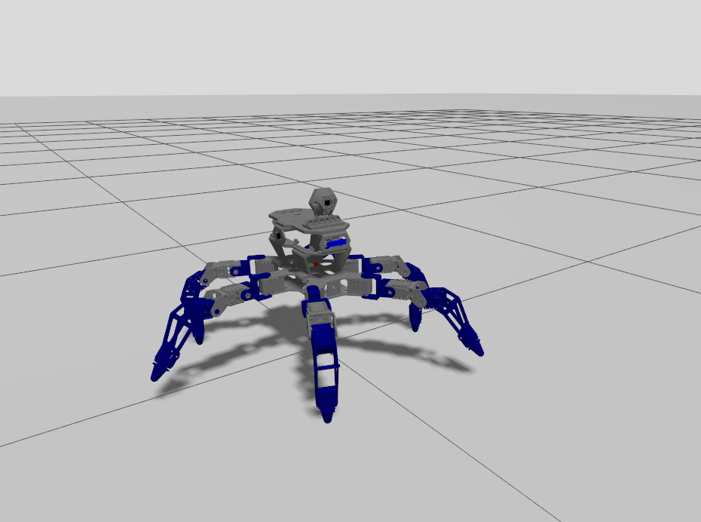
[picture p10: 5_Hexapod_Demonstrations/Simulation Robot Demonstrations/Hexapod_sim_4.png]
GPS Navigation — view 4
  
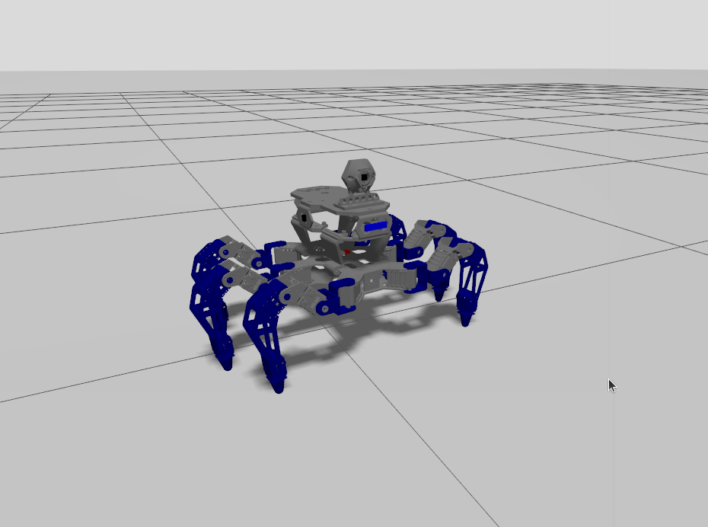
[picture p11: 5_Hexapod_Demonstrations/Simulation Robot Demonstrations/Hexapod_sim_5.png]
GPS Navigation — view 5
  
  GPS Navigation Map
</p>

---

## 🎬 Video Index

> **How to watch:** Click the thumbnail or title to open the video on YouTube.  
> Thumbnails are taken from the simulation screenshots above.

---

### Part 1 — Gazebo Launch

**File:** `1_Hexapod_gazebo_launch.mp4`  
**Title:** *Hexapod Project - Simulation Part 1 (Gazebo Launch)*

<p align="center">
  <a href="https://youtu.be/VrdOxer3bfk">
    ▶ Watch: Gazebo Launch
  </a>
</p>
<p align="center"><em>▶ Click to watch on YouTube</em></p>

**Description:**  
In this first simulation video, I launch the full Gazebo + ROS2 environment for my hexapod robot project. You'll see the robot model being spawned into the virtual world, the ros2_control joints initializing, and the complete simulation pipeline coming to life.

This is the **mandatory first step** before running any behavior mode — Gazebo provides the physics engine, sensor simulation, and the communication bridge between the robot and the ROS2 nodes.

**Stack:** `ROS2 Jazzy` · `Gazebo Harmonic` · `ros_gz_bridge` · `URDF/XACRO`

**Launch command:**
```bash
ros2 launch hexapod_pkg gazebo_hexapod_sim.launch.py
```

---

### Part 2 — Teleoperation

**File:** `2_Hexapod_teleop_node_sim.mp4`  
**Title:** *Hexapod Project - Simulation Part 2 (Teleoperation)*

<p align="center">
  <a href="https://youtu.be/bPy6ompV-m8">
    ▶ Watch: Teleoperation
  </a>
</p>
<p align="center"><em>▶ Click to watch on YouTube</em></p>

**Description:**  
With the Gazebo simulation running, in this video I take manual control of the hexapod robot using the teleoperation node. Keyboard inputs are translated in real time into motion commands, controlling the direction and gait of the robot inside the simulated environment.

Teleop is a key tool for **debugging, calibration**, and verifying that the low-level control layer is working correctly before deploying any autonomous behavior.

**Stack:** `ROS2 Jazzy` · `Gazebo Harmonic` · `teleop_hexapod_sim node`

**Launch command:**
```bash
ros2 launch hexapod_pkg gazebo_hexapod_sim.launch.py
# Then in a new terminal:
ros2 run hexapod_pkg teleop_hexapod_sim
```

---

### Part 3 — Sensor Computation Layer

**File:** `3_Hexapod_sensors_compute_sim.mp4`  
**Title:** *Hexapod Project - Simulation Part 3 (Sensor Computation Layer)*

<p align="center">
  <a href="https://youtu.be/xsyxHJcdykU">
    ▶ Watch: Sensor Computation Layer
  </a>
</p>
<p align="center"><em>▶ Click to watch on YouTube</em></p>

**Description:**  
Before enabling any autonomous navigation, the sensor computation layer must be active. This launch processes raw Gazebo sensor data into high-level signals:

- 📍 GPS lat/lon → local XY coordinates
- 🧭 IMU + magnetometer → heading angle
- 📐 Dead-reckoning position estimate
- 📡 Ultrasonic → obstacle distances in meters
- 🔎 Master monitor for system health

This "nervous system" layer is what allows the robot to know **where it is** and **what's around it**.

**Stack:** `ROS2 Jazzy` · `Gazebo` · `GPS` · `IMU` · `Ultrasonic sensors`

**Launch command:**
```bash
# Terminal 1
ros2 launch hexapod_pkg gazebo_hexapod_sim.launch.py
# Terminal 2
ros2 launch hexapod_pkg sensors_compute_sim.launch.py
```

---

### Part 4 — Vision-Based Follower

**File:** `4_Hexapod_follower_sim.mp4`  
**Title:** *Hexapod Project - Simulation Part 4 (Vision-Based Follower)*

<p align="center">
  <a href="https://youtu.be/TKISpMUWDwg">
    ▶ Watch: Vision-Based Follower
  </a>
</p>
<p align="center"><em>▶ Click to watch on YouTube</em></p>

**Description:**  
In this demo, the hexapod autonomously follows a moving object detected by the camera using a **YOLO-based computer vision model**. The robot continuously tracks the target's position in the image and generates reactive motion commands to pursue it while avoiding obstacles.

This mode showcases the integration between the vision pipeline (YOLO inference) and the navigation layer running entirely inside Gazebo simulation.

**Stack:** `ROS2 Jazzy` · `Gazebo` · `YOLO (Ultralytics)` · `PyTorch`

**Launch command:**
```bash
ros2 launch hexapod_pkg gazebo_hexapod_sim.launch.py
ros2 launch hexapod_pkg sensors_compute_sim.launch.py
ros2 launch hexapod_pkg follower_sim.launch.py
```

---

### Part 5 — Swarm Follower

**File:** `5_Hexapod_swarm_follower_sim.mp4`  
**Title:** *Hexapod Project - Simulation Part 5 (Swarm Follower)*

<p align="center">
  <a href="https://youtu.be/z2tB1xrgj1U">
    ▶ Watch: Swarm Follower
  </a>
</p>
<p align="center"><em>▶ Click to watch on YouTube</em></p>

**Description:**  
This video demonstrates the **swarm follower mode** — a behavior designed to scale to multiple robots operating collectively. Using YOLO-based detection and obstacle-aware navigation, the hexapod follows a target using coordination logic inspired by swarm robotics principles.

In single-robot mode (shown here), the swarm logic collapses into a compact follower behavior, but the architecture is ready to support multiple agents.

**Stack:** `ROS2 Jazzy` · `Gazebo` · `YOLO` · `Swarm navigation node`

**Launch command:**
```bash
ros2 launch hexapod_pkg gazebo_hexapod_sim.launch.py
ros2 launch hexapod_pkg sensors_compute_sim.launch.py
ros2 launch hexapod_pkg swarm_follower_sim.launch.py
```

---

### Part 6 — Autonomous GPS Navigation

**File:** `6_Hexapod_gps_navigation_sim.mp4`  
**Title:** *Hexapod Project - Simulation Part 6 (Autonomous GPS Navigation)*

<p align="center">
  <a href="https://youtu.be/vps-d9vtT4c">
    ▶ Watch: Autonomous GPS Navigation
  </a>
</p>
<p align="center"><em>▶ Click to watch on YouTube</em></p>

**Description:**  
Full autonomous navigation to a GPS target with real-time obstacle avoidance — all inside Gazebo simulation.

The hexapod uses:
- 🛰️ Simulated GPS for global positioning
- 📐 Dead-reckoning for position estimation
- 👁️ YOLO vision for target detection (cube)
- 📡 Ultrasonic sensors for obstacle awareness
- 🔄 A continuous replanning navigation loop

This is the **most complex simulation mode**, combining all the sensor and navigation layers into a unified autonomous system.

**Stack:** `ROS2 Jazzy` · `Gazebo` · `GPS` · `YOLO` · `Obstacle Avoidance`

**Launch command:**
```bash
ros2 launch hexapod_pkg gazebo_hexapod_sim.launch.py
ros2 launch hexapod_pkg sensors_compute_sim.launch.py
ros2 launch hexapod_pkg navigation_to_target_sim.launch.py
```

---

### Part 7 — Social Robot (Hand Gestures)

**File:** `7_Hexapod_social_robot_launch_sim.mp4`  
**Title:** *Hexapod Project - Simulation Part 7 (Social Robot — Hand Gestures)*

<p align="center">
  <a href="https://youtu.be/Hdm6wiWA3Ro">
    ▶ Watch: Social Robot — Hand Gestures
  </a>
</p>
<p align="center"><em>▶ Click to watch on YouTube</em></p>

**Description:**  
In this final simulation demo, the hexapod responds to human hand gestures captured by the camera. Using **MediaPipe landmark detection**, specific gestures are recognized and translated into symbolic robot actions:

| Gesture | Robot Reaction |
|---|---|
| ROCK | Aggressive pose / stomp |
| VICTORY | Celebration sequence |
| AL_PELO | Custom expressive motion |

This social interaction layer is purely experimental, exploring how a hexapod can act as an **expressive social robot** — reacting to its human partner in real time.

**Stack:** `ROS2 Jazzy` · `Gazebo` · `MediaPipe` · `OpenCV` · `hand_gesture_node`

**Launch command:**
```bash
ros2 launch hexapod_pkg gazebo_hexapod_sim.launch.py
ros2 launch hexapod_pkg social_robot_sim.launch.py
```

---

## Common Setup (All Simulation Modes)

```bash
# 1. Source ROS2 and workspace
source /opt/ros/jazzy/setup.bash
source ~/ros2_hexapod_ws/install/setup.bash

# 2. (Modes with YOLO) Activate Python venv
source ~/.venvs/yolo/bin/activate

# 3. Launch Gazebo (ALWAYS first)
ros2 launch hexapod_pkg gazebo_hexapod_sim.launch.py
```

> Full setup instructions: [1_ROS2_Gazebo_Project/README.md](../../1_ROS2_Gazebo_Project/README.md)

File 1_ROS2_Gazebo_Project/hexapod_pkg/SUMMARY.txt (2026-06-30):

============================================================
HEXAPOD PROJECT — SYSTEM OVERVIEW
============================================================

------------------------------------------------------------
CORE IDEA
------------------------------------------------------------

This project implements a **dual-execution hexapod architecture**:

- One logical brain
- Two physical realities

The same high-level behaviors operate on:
- a Gazebo simulation
- a real hexapod robot

The difference is NOT in intelligence,
but in the **final actuation layer**.

------------------------------------------------------------
DUALITY: SIMULATION vs REAL ROBOT
------------------------------------------------------------

The system is intentionally split into two worlds:

SIMULATION:
-----------
- Gazebo + ros_gz_bridge
- Physics-based feedback
- Visual social behaviors
- No hardware constraints
- Fast iteration and debugging

REAL ROBOT:
-----------
- Raspberry Pi + Arduino
- Real sensors, noise, latency
- No fake physics
- Strict hardware limits
- Physical consequences

------------------------------------------------------------
KEY UNIFYING PRINCIPLE
------------------------------------------------------------

All modes generate the same abstraction:

    std_msgs/String  →  "cmd_robot"

What changes is:
- where it is interpreted
- how it is executed
- how much freedom exists

------------------------------------------------------------
COMMAND PIPELINE (ABSTRACT)
------------------------------------------------------------

Behavior / Navigation / Social Logic
                ↓
        cmd_robot (String)
                ↓
------------------------------------
SIMULATION:
    gz_hexapod_low_level_control
        → joint trajectories

REAL ROBOT:
    dds_cmd_talker
        → serial protocol
        → Arduino firmware
------------------------------------

============================================================
MAIN MODES OF OPERATION
============================================================

------------------------------------------------------------
1) FOLLOWER MODE
------------------------------------------------------------

PURPOSE:
--------
Track and follow a moving visual target
(e.g. a ball or object).

PERCEPTION:
-----------
- Camera (YOLO-based detection)
- Target position in image space
- Obstacle occupation grid

CONTROL:
--------
- Relative motion generation
- Continuous correction
- Reactive behavior

SIMULATION:
-----------
- Perfect camera stream
- No motor backlash
- Visual validation of tracking

REAL ROBOT:
-----------
- Phone / USB camera
- Latency-sensitive
- Motion stability becomes critical

------------------------------------------------------------
2) NAVIGATION TO TARGET MODE
------------------------------------------------------------

PURPOSE:
--------
Move autonomously toward a global target
while avoiding obstacles.

PERCEPTION:
-----------
- GPS (global position)
- Heading (IMU / phone)
- Ultrasonic sensors
- IR proximity sensors

COMPUTATION:
------------
- GPS → local XY conversion
- Heading estimation
- Dead-reckoning fusion
- Obstacle monitoring

CONTROL:
--------
- Goal-oriented motion
- Obstacle avoidance
- Continuous replanning

CRITICAL NOTE:
--------------
`sensors_compute_*` launch MUST be running.
Without it, navigation is blind.

------------------------------------------------------------
3) SWARM FOLLOWER MODE
------------------------------------------------------------

PURPOSE:
--------
Follow a leader or group behavior
using minimal global information.

PERCEPTION:
-----------
- Visual target (YOLO)
- Obstacle occupation grid

CONTROL:
--------
- Collective-style motion
- Simplified navigation rules
- No global map dependency

SIMULATION:
-----------
- Multi-agent logic validation
- Behavior-level testing

REAL ROBOT:
-----------
- Acts as single agent
- Swarm logic collapses to follower logic
- Still useful as coordination prototype

------------------------------------------------------------
4) SOCIAL ROBOT MODE
------------------------------------------------------------

PURPOSE:
--------
Human–robot interaction via gestures.

PERCEPTION:
-----------
- Camera
- MediaPipe hand landmarks

LOGIC:
------
- Deterministic geometric gesture detection
- Event-based command generation

GESTURES:
---------
- ROCK
- AL_PELO
- VICTORY

SIMULATION:
-----------
- Gestures trigger symbolic poses
- Visual expressiveness
- Social meaning preserved

REAL ROBOT:
-----------
- Same gestures → motion commands
- No social poses in Arduino
- Semantics collapse into locomotion

IMPORTANT:
----------
Social meaning exists only
where interpretation exists.

------------------------------------------------------------
5) TELEOP MODE
------------------------------------------------------------

PURPOSE:
--------
Direct human control.

INPUT:
------
- Keyboard
- External controller
- Manual command publisher

ROLE:
-----
- Debugging
- Safety override
- Calibration
- Emergency control

SIMULATION & REAL:
------------------
Identical at command level.
Different only in execution risk.

============================================================
BALANCE CONTROLLER (EXTRA)
============================================================

PURPOSE:
--------
Maintain stability during motion
and compensate disturbances.

CONCEPTUAL ROLE:
----------------
This controller lives BELOW navigation
and ABOVE raw actuation.

INPUTS:
-------
- IMU
- Estimated body orientation
- Motion commands

FUNCTION:
---------
- Postural correction
- Roll / pitch stabilization
- Gait robustness improvement

SIMULATION:
-----------
- NO IMPLEMENTED YET!!!

REAL ROBOT:
-----------
- Compensates:
    - uneven terrain
    - servo delays
    - mechanical asymmetry

DESIGN PHILOSOPHY:
------------------
Balance is not intelligence.
It is *physiology*.

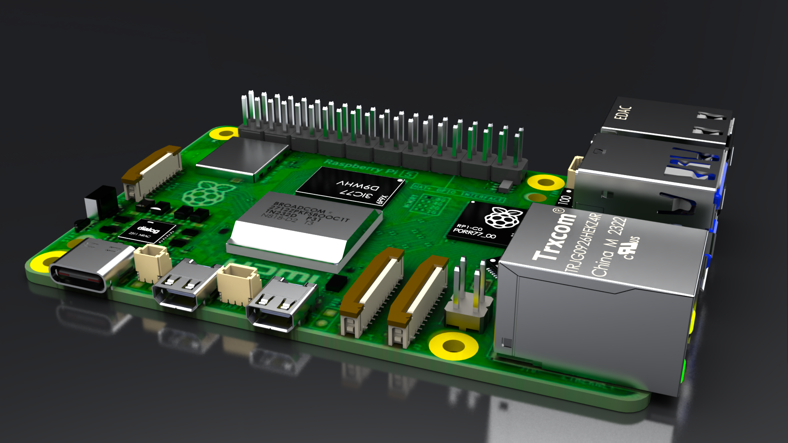
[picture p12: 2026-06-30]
3_3D_Design/Hexapod 3D model/pi5/RENDERS/Raspberry Pi 5_Ładny wygląd.png

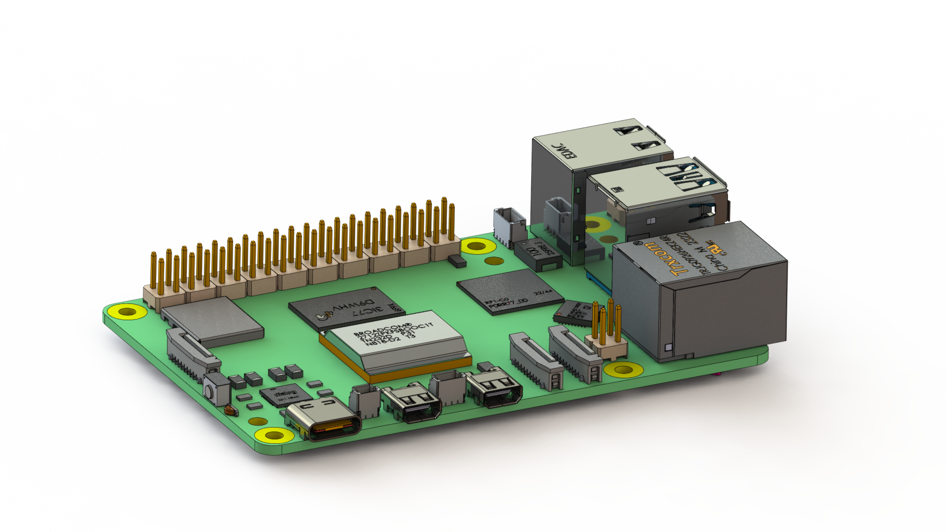
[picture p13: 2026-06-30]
3_3D_Design/Hexapod 3D model/pi5/RENDERS/RASPBERRY_PI_5_2.png

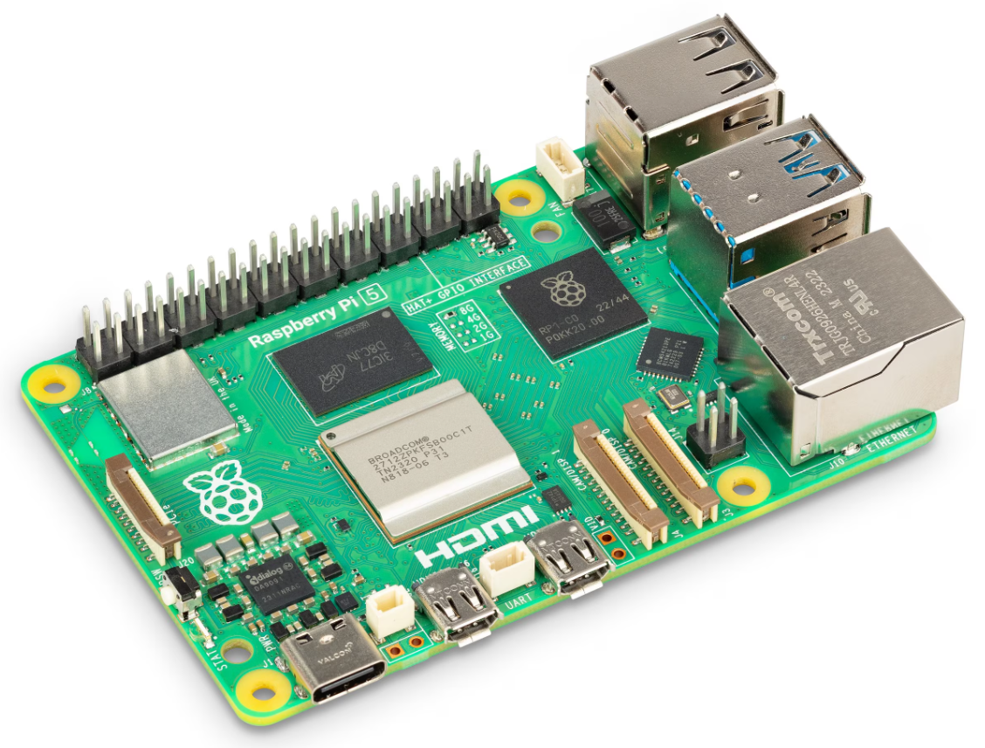
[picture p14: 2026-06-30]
3_3D_Design/Hexapod 3D model/pi5/Photo/raspberry pi 5.png

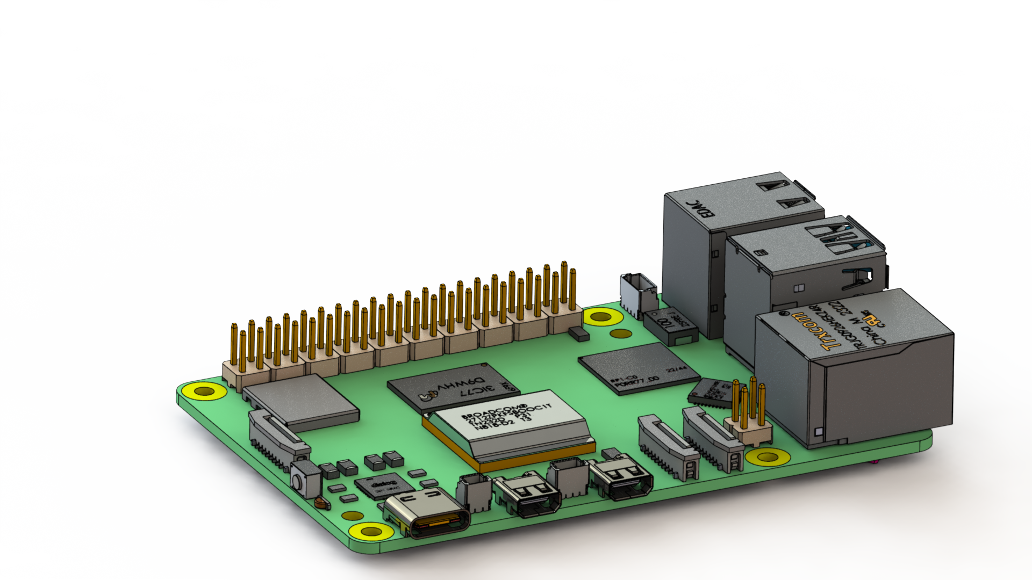
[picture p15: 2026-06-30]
3_3D_Design/Hexapod 3D model/pi5/RENDERS/RASPBERRY_PI_5_3.png

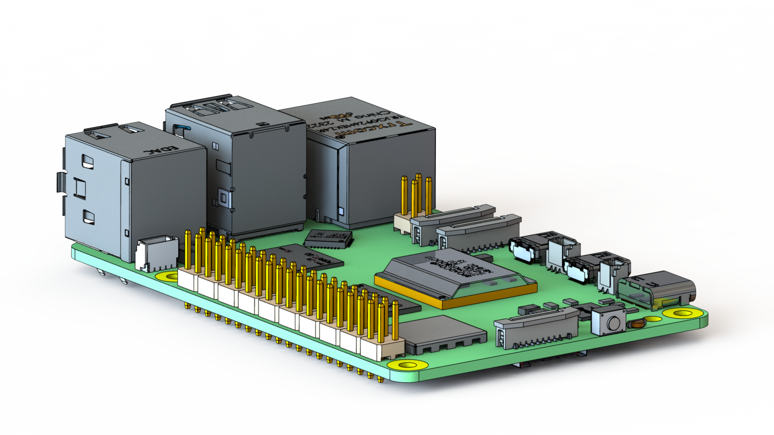
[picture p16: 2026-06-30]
3_3D_Design/Hexapod 3D model/pi5/RENDERS/RASPBERRY_PI_5_5.png

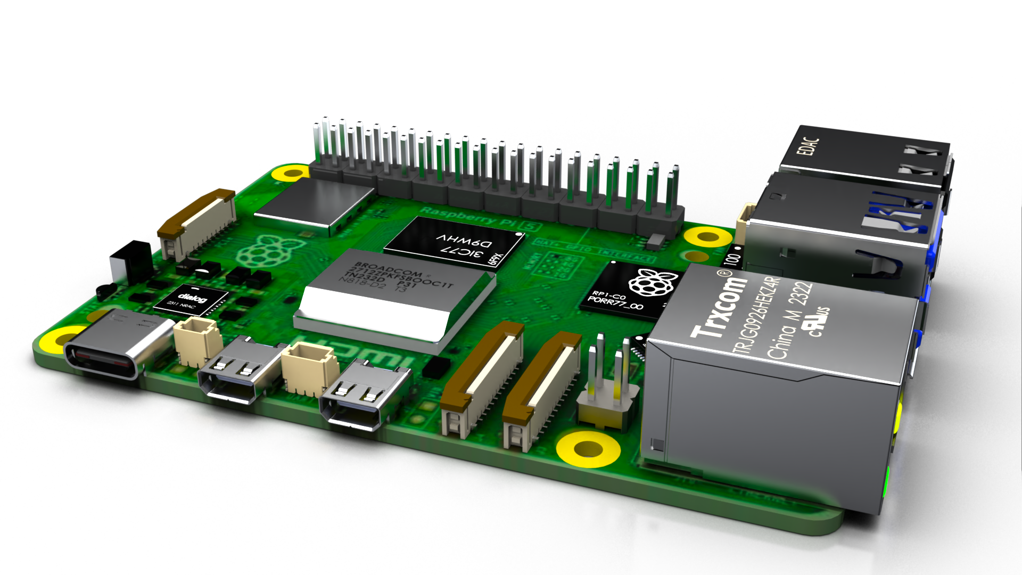
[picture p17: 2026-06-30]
3_3D_Design/Hexapod 3D model/pi5/RENDERS/Raspberry Pi (2)_Ładny wygląd.png

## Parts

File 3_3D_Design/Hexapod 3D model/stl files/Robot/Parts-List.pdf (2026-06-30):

Electronics Description | Notes
18 | MG996R Servo | I paid about $5 each on Amazon for MG996R clones in packs of 10 - mine were marked LKY62.
1 | YEP 20A HV (2~12S) SBEC | I removed the shrink wrap and remounted it in the 3D printed mount. Required resoldering the power leads.
1 | Mega 2560 (Arduino) | Mine is an arduino clone bought on ebay.
1 Logitech PS2 wireless controller (and receiver) I carefully removed the receiver circuit board from its case and remounted it in my new 3D printed mount.
1 | 5000mAh 3S 20C LiPo battery | This is what I had on-hand. Probably would work fine with a smaller mAh capacity (but I would still use a 3 cell 3S pack).
1 | Logic Level Converter | I bought mine on Amazon. Link on the webpage.

Electronics
Hardware | Description | Notes
1 | battery connector | I used XT60.

### 1 SPST toggle switch

2 | 7x15 perfboard | servo headers
1 | 9x17 perfboard | LED status display board
1 | 1N4004 diode | Keeps the Mega 2560 processor from back-powering the SBEC regulator when it's connected to a computer via its USB port.
1 | 1/8W 1K ohm resistor | used for the voltage divider to A0 input for battery monitoring
1 | 1/8W 2K ohm resistor | used for the voltage divider to A0 input for battery monitoring
8 | 1/8W 680 ohm resistor | LED status display board
8 | red/green bicolor common cathode LEDs | used for the LED status display board
misc | 3/4" velcro | used to mount the battery
misc | header strips | used for connection to the Mega 2560 processor and for the perfboards.
misc | wire | stranded ribbon cable (separated) for signal wires, heavier stranded wire for power

Mechanical
Hardware | Description | Notes
18 | 624Z Bearing | I bought mine on ebay.
54 | 4-40 nuts | Bought in packs of 100 from McMaster-Carr (90480A005) https://www.mcmaster.com/90480A005
210 | 4-40 x 3/8" machine screws | Bought in packs of 100 from McMaster-Carr (90272A108) https://www.mcmaster.com/90272A108
96 | 4-40 x 1/2" machine screws | Bought in packs of 100 from McMaster-Carr (90272A110) https://www.mcmaster.com/90272A110
12 | 4-40 x 5/8" machine screws | Bought in packs of 100 from McMaster-Carr (90272A112) https://www.mcmaster.com/90272A112
84 | #2 1/4" screws | Bought in packs of 100 from McMaster-Carr (92470A095) https://www.mcmaster.com/92470A095

3D Printed
Parts | Description | Notes
1 | Body Bottom Plate | Printed at 30% infill, no support needed
6 | Body Riser | Printed at 30% infill, no support needed
1 | Body Top Plate | Printed at 30% infill, no support needed
12 | Femur Bracket End Cap | Printed at 30% infill, no support needed
12 | Femur Bracket | Printed at 30% infill, no support needed
1 | Receiver Holder | Printed at 30% infill, with support.
1 | SBEC Holder | Printed at 30% infill, with support.
18 | Servo Bearing Center | Printed at 30% infill, no support needed
18 | Servo Mount | Printed at 30% infill, with support.
6 | Tibia Base Plate | Printed at 30% infill, no support needed
6 | Tibia Bracket End Cap | Printed at 30% infill, no support needed
6 | Tibia Bracket | Printed at 30% infill, no support needed
6 | Tibia Foot Bumper | Printed in TPU, 10% infill, no support needed
6 | Tibia Foot Plate | Printed at 30% infill, no support needed
6 | Tibia Side 1 | Printed at 30% infill, no support needed. Sides are identical, just printed with opposing sides down.
6 | Tibia Side 2 | Printed at 30% infill, no support needed. Sides are identical, just printed with opposing sides down.
6 | Tibia Spacer Tube | Printed at 30% infill, no support needed
6 | Wire Guide | Printed at 30% infill, with support.

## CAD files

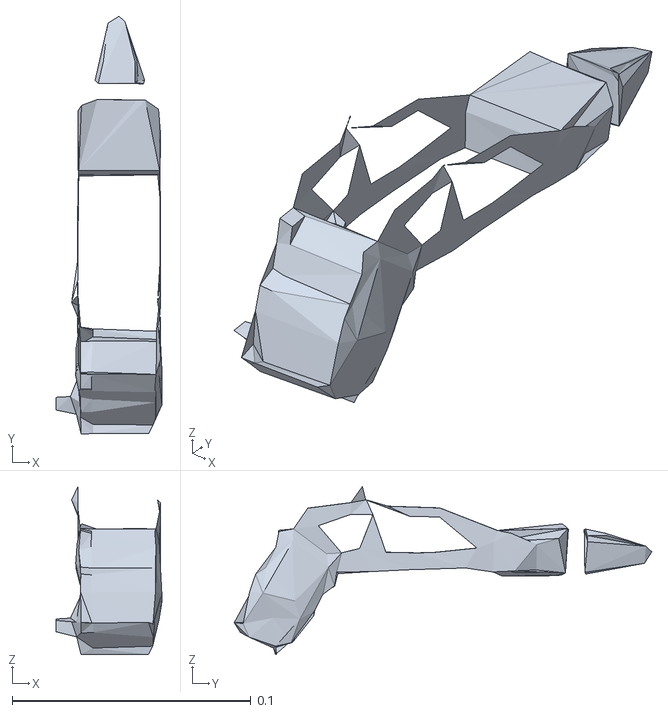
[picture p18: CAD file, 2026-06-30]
1_ROS2_Gazebo_Project/hexapod_pkg/meshes/tibia_l_coll.STL
0.0445 x 0.175 x 0.0704

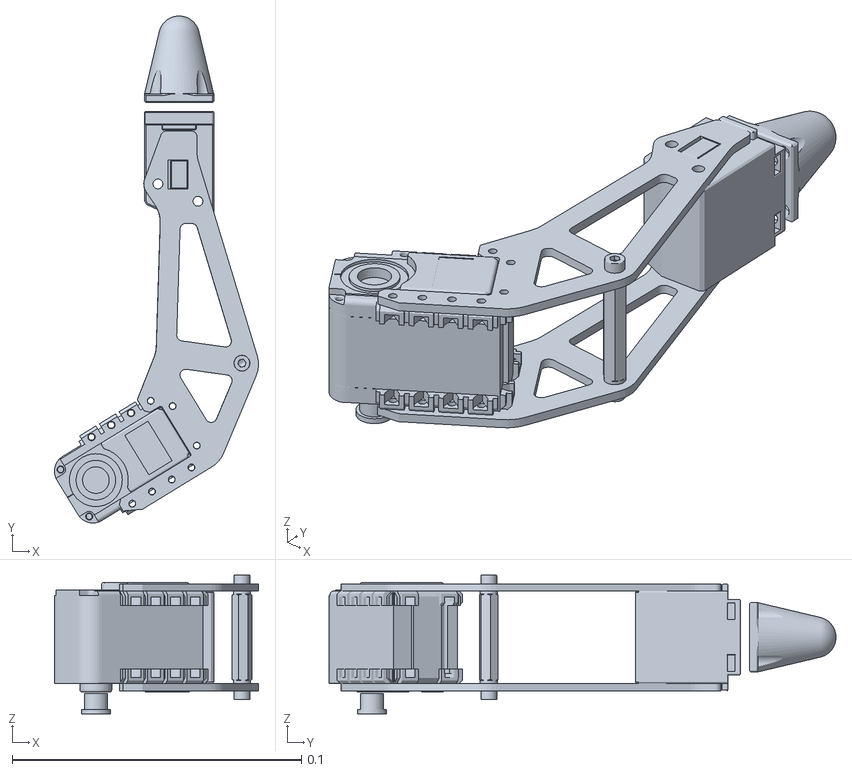
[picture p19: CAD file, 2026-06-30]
1_ROS2_Gazebo_Project/hexapod_pkg/meshes/tibia_r.STL
0.0706 x 0.175 x 0.048

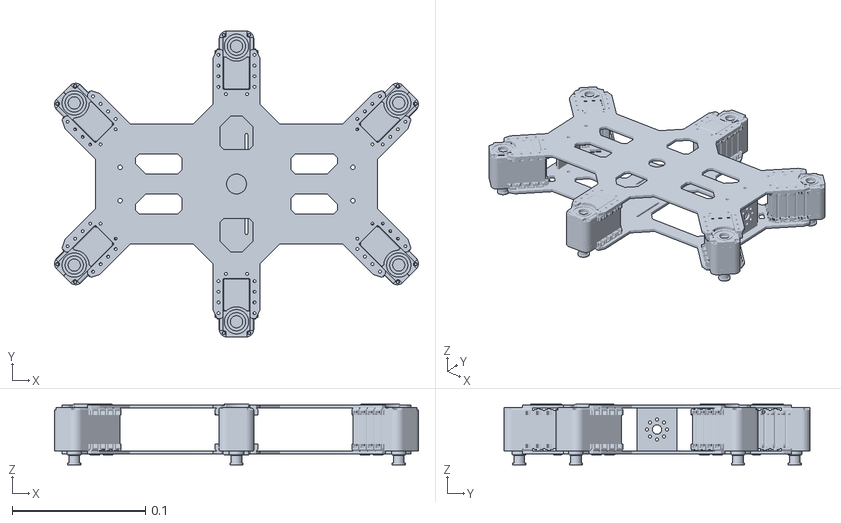
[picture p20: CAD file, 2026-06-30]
1_ROS2_Gazebo_Project/hexapod_pkg/meshes/body.STL
0.273 x 0.23 x 0.0455

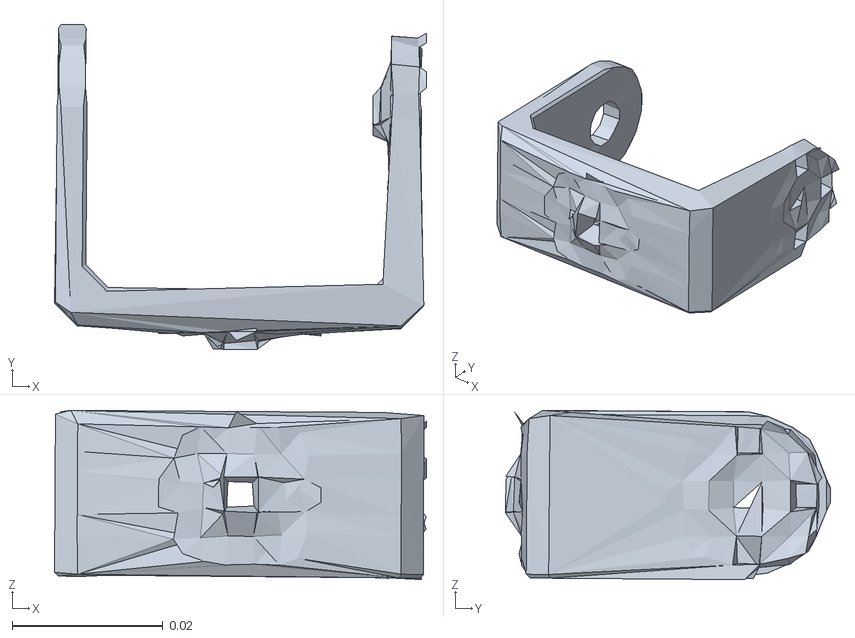
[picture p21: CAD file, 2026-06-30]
1_ROS2_Gazebo_Project/hexapod_pkg/meshes/connect_coll.STL
0.0494 x 0.0432 x 0.0225

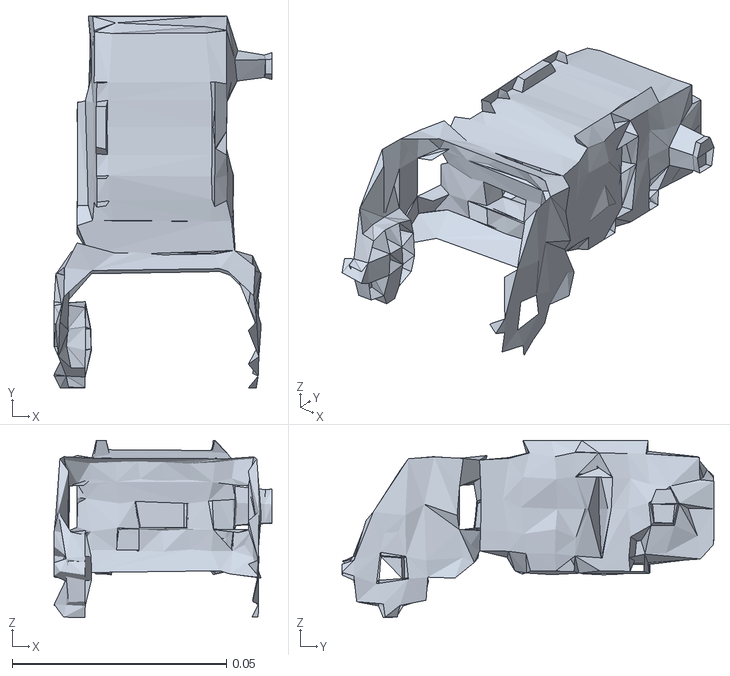
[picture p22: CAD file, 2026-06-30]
1_ROS2_Gazebo_Project/hexapod_pkg/meshes/thigh_l_coll.STL
0.0509 x 0.0869 x 0.0414

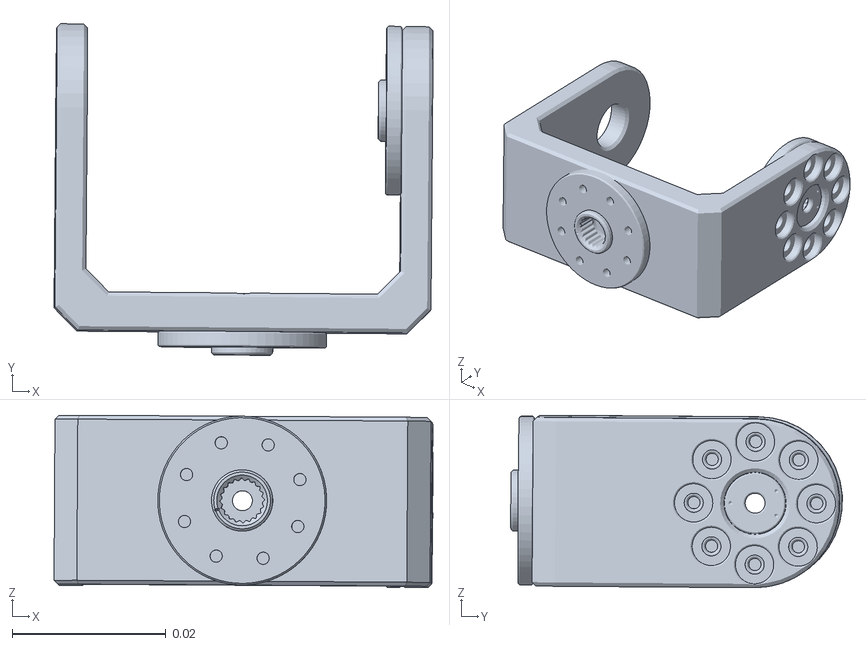
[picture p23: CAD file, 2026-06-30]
1_ROS2_Gazebo_Project/hexapod_pkg/meshes/connect.STL
0.0494 x 0.0432 x 0.0225

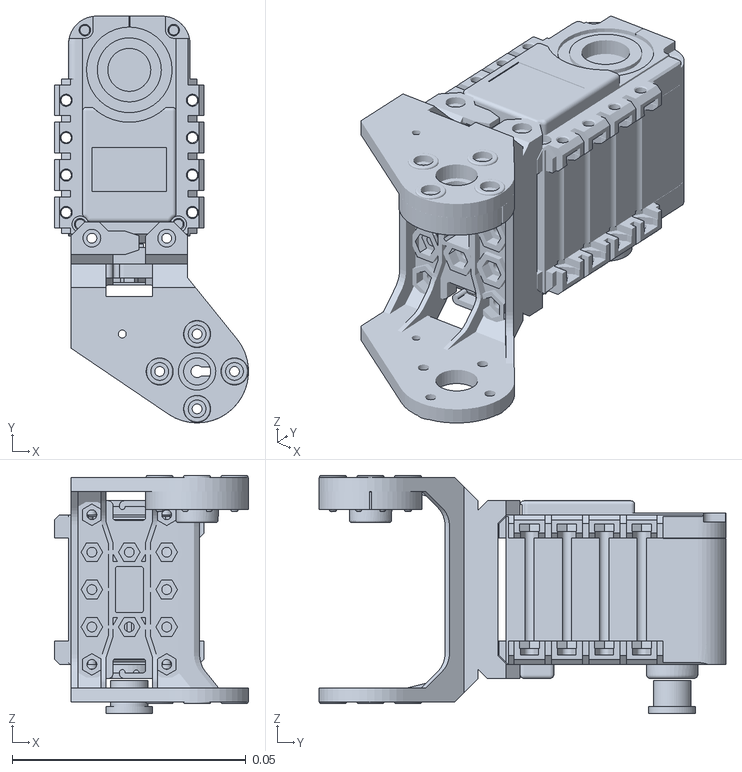
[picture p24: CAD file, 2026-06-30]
1_ROS2_Gazebo_Project/hexapod_pkg/meshes/thigh_r.STL
0.0415 x 0.087 x 0.0509

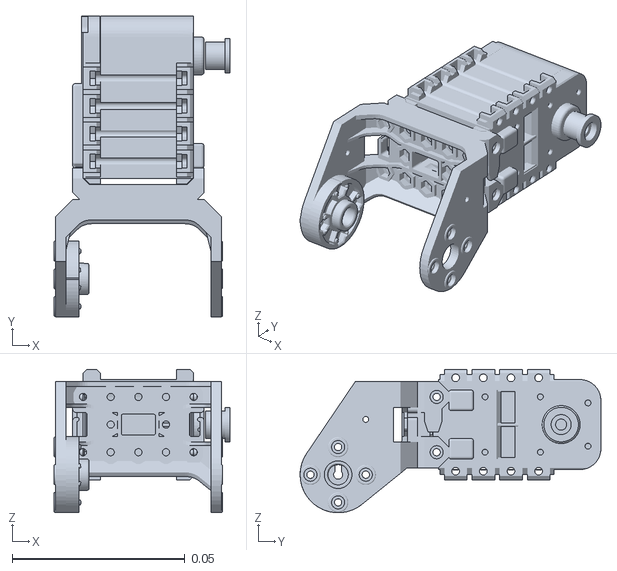
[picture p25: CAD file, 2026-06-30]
1_ROS2_Gazebo_Project/hexapod_pkg/meshes/thigh_l.STL
0.0509 x 0.087 x 0.0415

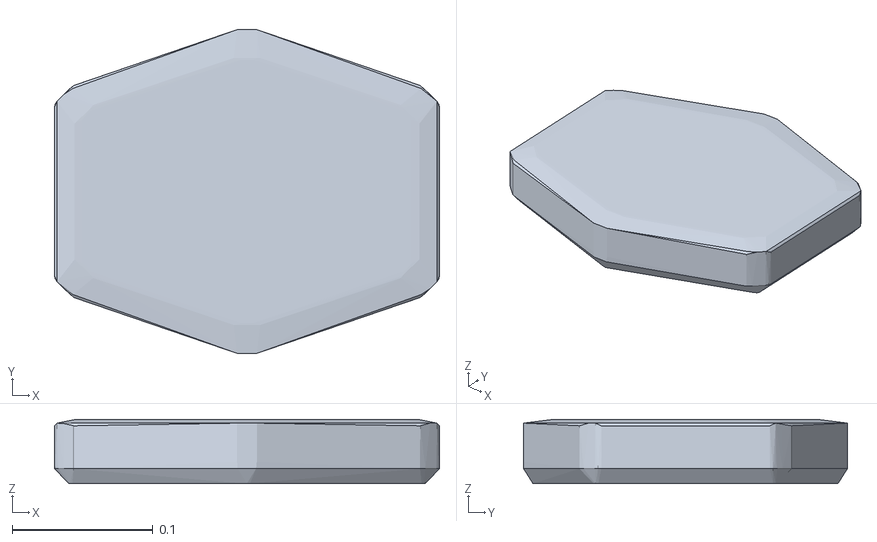
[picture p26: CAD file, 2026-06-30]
1_ROS2_Gazebo_Project/hexapod_pkg/meshes/body_coll.STL
0.273 x 0.23 x 0.0455

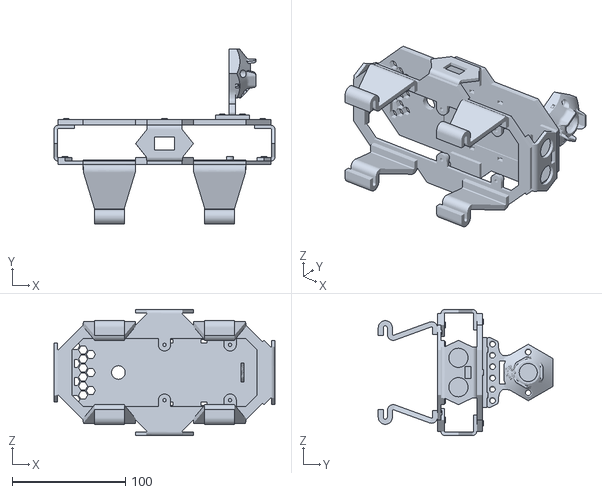
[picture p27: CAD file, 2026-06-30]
1_ROS2_Gazebo_Project/hexapod_pkg/meshes/holder_pi_uttu.STL
195.5 x 154.3 x 111.5

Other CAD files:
1_ROS2_Gazebo_Project/hexapod_pkg/meshes/tibia_l.STL
3_3D_Design/Hexapod 3D model/JS40F/JS40F Sensor/JS40F v1.f3d

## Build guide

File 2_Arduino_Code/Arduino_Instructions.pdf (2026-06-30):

Instrucciones Arduino:
HELP → imprime la lista.
MODE n (0 idle, 1 walk, 2 translate, 3 rotate, 4 leg lift, 99 set_all_90) y GAIT n (0‑3) cambian modos sin necesidad de “botones”.
SPEED 0|1 selecciona velocidad rápida/lenta del gait.
WALK x y r fija los vectores de traslación/rotación para los gaits (rangos −127…127, mismo significado que antes).
TRANS x y z y ROT rx ry rz z controlan traslaciones (±2·TRAVEL mm en X/Y, −3·TRAVEL…TRAVEL en Z) y rotaciones (±12° en roll/pitch, ±30° en yaw) usadas en los modos 2 y 3.
LEG1 coxa femur tibia y LEG6 … llevan directamente esos dos extremos al ángulo indicado (45‑135° para coxa, 0‑170° femur/tibia) durante el modo 4.
STEPH n (1‑8) ajusta la altura de paso y actualiza step_height_multiplier, mientras
CAPTURE bloquea offsets en modos 2/3 y CLEAROFF los borra.
RESET vuelve a home, SET90 entra en calibración, y cualquier comando desconocido responde con “Comando desconocido”.

Modos 2 y 3 desechados, e incluidos en MODE 1, CAPTURE Y CLEAROFF por consecuencia tambien.

Flujo de operaciones:
MODE 1
WALK x y r (WALK 60 0 -3, -3 siempre para corregir el desfase en movimiento) ROT rx ry rz z (ROT 0 5 0 0, maximo 12 grados)
WALK 0 0 0 para parar

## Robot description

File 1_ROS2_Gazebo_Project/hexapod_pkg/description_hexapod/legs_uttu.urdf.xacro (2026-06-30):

<?xml version="1.0"?>
<robot xmlns:xacro="http://ros.org/wiki/xacro">

<xacro:include filename="legs_uttu.gazebo.xacro"/>

  <!-- Propiedades comunes -->
  <xacro:property name="connect_offset" value="0.02633"/>
  <xacro:property name="thigh_offset_y" value="-0.0645"/>
  <xacro:property name="thigh_offset_z" value="-0.0145"/>

  <!-- Macro principal de la pierna -->
  <xacro:macro name="leg_uttu_v0" params="parent xyz rpy suffix">

    <!-- ===================== -->
    <!--   JOINT C1 -> Cuerpo  -->
    <!-- ===================== -->
    <joint name="j_c1_${suffix}" type="revolute">
      <parent link="${parent}"/>
      <child link="c1_${suffix}"/>
      <origin xyz="${xyz}" rpy="${rpy}"/>
      <axis xyz="1 0 0"/>
      <limit effort="2.8" velocity="5.6548668" lower="-2.6179939" upper="2.6179939"/>
    </joint>

    <!-- ===================== -->
    <!--   LINK C1             -->
    <!-- ===================== -->
    <link name="c1_${suffix}">
      <inertial>
        <origin xyz="0 -${connect_offset} 0"/>
        <mass value="0.01"/>
        <inertia ixx="0.00" ixy="0.00" ixz="0.00" iyy="0.00" iyz="0.00" izz="0.00" />
      </inertial>

      <visual>
        <origin xyz="0 -0.0252 0"/>
        <geometry>
          <mesh filename="$(find hexapod_pkg)/meshes/connect.STL"/>
        </geometry>
          <material name="Blue">
            <color rgba="0.0 0.0 0.2 1.0"/>
          </material>
      </visual>

      <collision>
        <origin xyz="0 -${connect_offset} 0"/>
        <geometry>
          <mesh filename="$(find hexapod_pkg)/meshes/connect_coll.STL"/>
        </geometry>
      </collision>
    </link>

    <!-- ===================== -->
    <!--   JOINT C2 -> C1      -->
    <!-- ===================== -->
    <joint name="j_c2_${suffix}" type="fixed">
      <parent link="c1_${suffix}"/>
      <child link="c2_${suffix}"/>
      <origin xyz="0 -0.054 0" rpy="0 1.5704 3.14159"/>
    </joint>

    <!-- ===================== -->
    <!--   LINK C2             -->
    <!-- ===================== -->
    <link name="c2_${suffix}">
      <inertial>
        <origin xyz="0 -${connect_offset} 0"/>
        <mass value="0.01"/>
        <inertia ixx="0.00" ixy="0.00" ixz="0.00" iyy="0.00" iyz="0.00" izz="0.00" />
      </inertial>

    <visual>
      <origin xyz="0 -0.0252 0"/>
      <geometry>
        <mesh filename="$(find hexapod_pkg)/meshes/connect.STL"/>
      </geometry>
          <material name="Blue">
            <color rgba="0.0 0.0 0.2 1.0"/>
          </material>
    </visual>

    <collision>
        <origin xyz="0 -${connect_offset} 0"/>
        <geometry>
          <mesh filename="$(find hexapod_pkg)/meshes/connect_coll.STL"/>
        </geometry>
      </collision>
    </link>

    <!-- ===================== -->
    <!--   JOINT THIGH         -->
    <!-- ===================== -->
    <joint name="j_thigh_${suffix}" type="revolute">
      <parent link="c2_${suffix}"/>
      <child link="thigh_${suffix}"/>
      <origin xyz="0 0 0" rpy="0 3.14159 3.14159"/>
      <axis xyz="1 0 0"/>
      <limit effort="2.8" velocity="5.6548668" lower="-2.6179939" upper="2.6179939"/>
    </joint>

    <!-- ===================== -->
    <!--   LINK THIGH          -->
    <!-- ===================== -->
    <link name="thigh_${suffix}">
      <inertial>
        <origin xyz="0 0 0"/>
        <mass value="0.05"/>
        <inertia ixx="0.00" ixy="0.00" ixz="0.00" iyy="0.00" iyz="0.00" izz="0.00" />
      </inertial>

      <visual>
        <origin xyz="0 0 0"/>
        <geometry>
          <mesh filename="$(find hexapod_pkg)/meshes/thigh_l.STL"/>
        </geometry>
          <material name="Grey">
            <color rgba="0.20 0.20 0.20 1.0"/>
          </material>
      </visual>

      <collision>
        <origin xyz="0 0 0"/>
        <geometry>
          <mesh filename="$(find hexapod_pkg)/meshes/thigh_l_coll.STL"/>
        </geometry>
      </collision>
    </link>

    <!-- ===================== -->
    <!--   JOINT TIBIA         -->
    <!-- ===================== -->
    <joint name="j_tibia_${suffix}" type="revolute">
      <parent link="thigh_${suffix}"/>
      <child link="tibia_${suffix}"/>
      <origin xyz="0 ${thigh_offset_y} ${thigh_offset_z}" rpy="-1.5707 0 3.14159"/>
      <axis xyz="1 0 0"/>
      <limit effort="2.8" velocity="5.6548668" lower="-2.6179939" upper="2.6179939"/>
    </joint>

    <!-- ===================== -->
    <!--   LINK TIBIA          -->
    <!-- ===================== -->
    <link name="tibia_${suffix}">
      <inertial>
        <origin xyz="0 0 0"/>
        <mass value="0.06"/>
        <inertia ixx="0.01" ixy="0.00" ixz="0.00" iyy="0.01" iyz="0.00" izz="0.01" />
      </inertial>

      <visual>
        <origin xyz="0 0 0"/>
        <geometry>
          <mesh filename="$(find hexapod_pkg)/meshes/tibia_l.STL"/>
        </geometry>
          <material name="Blue">
            <color rgba="0.0 0.0 0.2 1.0"/>
          </material>
      </visual>

      <collision>
        <origin xyz="0 0 0"/>
        <geometry>
          <mesh filename="$(find hexapod_pkg)/meshes/tibia_l_coll.STL"/>
        </geometry>
      </collision>
    </link>

  <!-- ===================== -->
  <!--   TRANSMISSION         -->
  <!-- ===================== -->

  <transmission name="t_c1_${suffix}">
    <type>transmission_interface/SimpleTransmission</type>
    <joint name="j_c1_${suffix}">
      <hardwareInterface>EffortJointInterface</hardwareInterface>    
    </joint>
    <actuator name="m_c1_${suffix}">
      <hardwareInterface>EffortJointInterface</hardwareInterface>
      <mechanicalReduction>1</mechanicalReduction>
    </actuator>
  </transmission>


   <transmission name="t_thigh_${suffix}">
    <type>transmission_interface/SimpleTransmission</type>
    <joint name="j_thigh_${suffix}">
      <hardwareInterface>EffortJointInterface</hardwareInterface>    
    </joint>
    <actuator name="m_thigh_${suffix}">
      <hardwareInterface>EffortJointInterface</hardwareInterface>
      <mechanicalReduction>1</mechanicalReduction>
    </actuator>
  </transmission>


   <transmission name="t_tibia_${suffix}">
    <type>transmission_interface/SimpleTransmission</type>
    <joint name="j_tibia_${suffix}">
      <hardwareInterface>EffortJointInterface</hardwareInterface>
    </joint>
    <actuator name="m_tibia_${suffix}">
      <hardwareInterface>EffortJointInterface</hardwareInterface>
      <mechanicalReduction>1</mechanicalReduction>
    </actuator>
  </transmission>

  </xacro:macro>
</robot>

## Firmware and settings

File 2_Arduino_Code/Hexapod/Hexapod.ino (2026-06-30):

//***********************************************************************
// Hexapod Program
// Code for Arduino Mega
//***********************************************************************

//***********************************************************************
// IK and Hexapod gait references:
//  https://www.projectsofdan.com/?cat=4
//  http://www.gperco.com/2015/06/hex-inverse-kinematics.html
//  http://virtual-shed.blogspot.com/2012/12/hexapod-inverse-kinematics-part-1.html
//  http://virtual-shed.blogspot.com/2013/01/hexapod-inverse-kinematics-part-2.html
//  https://www.robotshop.com/community/forum/t/inverse-kinematic-equations-for-lynxmotion-3dof-legs/21336
//  http://arduin0.blogspot.com/2012/01/inverse-kinematics-ik-implementation.html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
//***********************************************************************

//***********************************************************************
// Includes
//***********************************************************************
#include <Servo.h>
#include <math.h>
#include <string.h>
#include <ctype.h>

//***********************************************************************
// Constant Declarations
//***********************************************************************
const int BATT_VOLTAGE = 0;
float voltage = 0;          // 12V Battery analog voltage input port
const int COXA1_SERVO = 37; // servo port definitions
const int FEMUR1_SERVO = 39;
const int TIBIA1_SERVO = 41;
const int COXA2_SERVO = 43;
const int FEMUR2_SERVO = 45;
const int TIBIA2_SERVO = 47;
const int COXA3_SERVO = 49;
const int FEMUR3_SERVO = 51;
const int TIBIA3_SERVO = 53;
const int COXA4_SERVO = 19;
const int FEMUR4_SERVO = 21;
const int TIBIA4_SERVO = 23;
const int COXA5_SERVO = 25;
const int FEMUR5_SERVO = 27;
const int TIBIA5_SERVO = 29;
const int COXA6_SERVO = 31;
const int FEMUR6_SERVO = 33;
const int TIBIA6_SERVO = 35;

const int COXA_LENGTH = 51; // leg part lengths
const int FEMUR_LENGTH = 65;
const int TIBIA_LENGTH = 121;

const int TRAVEL = 30; // translate and rotate travel limit constant

const long A12DEG = 209440; // 12 degrees in radians x 1,000,000
const long A30DEG = 523599; // 30 degrees in radians x 1,000,000

const int FRAME_TIME_MS = 20; // frame time (20msec = 50Hz)

const float HOME_X[6] = {82.0, 0.0, -82.0, -82.0, 0.0, 82.0}; // coxa-to-toe home positions
const float HOME_Y[6] = {82.0, 116.0, 82.0, -82.0, -116.0, -82.0};
const float HOME_Z[6] = {-80.0, -80.0, -80.0, -80.0, -80.0, -80.0};

const float BODY_X[6] = {110.4, 0.0, -110.4, -110.4, 0.0, 110.4}; // body center-to-coxa servo distances
const float BODY_Y[6] = {58.4, 90.8, 58.4, -58.4, -90.8, -58.4};
const float BODY_Z[6] = {0.0, 0.0, 0.0, 0.0, 0.0, 0.0};

const int COXA_CAL[6] = {2, -1, 0, 0, -2, -4}; // servo calibration constants
const int FEMUR_CAL[6] = {-5, 3, -3, 2, -4, 0};
const int TIBIA_CAL[6] = {-3, -4, -5, 5, 0, -4};

//***********************************************************************
// Variable Declarations
//***********************************************************************
unsigned long currentTime; // frame timer variables
unsigned long previousTime;

int temp; // mode and control variables
int mode;
int gait;
int gait_speed;
int reset_position;

int batt_voltage;

float L0, L3; // inverse kinematics variables
float gamma_femur;
float phi_tibia, phi_femur;
float theta_tibia, theta_femur, theta_coxa;

int leg1_IK_control, leg6_IK_control; // leg lift mode variables
float leg1_coxa, leg1_femur, leg1_tibia;
float leg6_coxa, leg6_femur, leg6_tibia;

int leg_num; // positioning and walking variables
int totalX, totalY, totalZ;
int tick, duration, numTicks;
int commandedX, commandedY, commandedR;
float step_height_multiplier;
float strideX, strideY, strideR;
float sinRotX, sinRotY, sinRotZ;
float cosRotX, cosRotY, cosRotZ;
float rotOffsetX, rotOffsetY, rotOffsetZ;
float amplitudeX, amplitudeY, amplitudeZ;
float offset_X[6], offset_Y[6], offset_Z[6];
float current_X[6], current_Y[6], current_Z[6];

// serial control variables
int walk_command_X = 0;
int walk_command_Y = 0;
int walk_command_R = 0;
int translate_command_X = 0;
int translate_command_Y = 0;
int translate_command_Z = 0;
int rotate_command_RX = 0;
int rotate_command_RY = 0;
int rotate_command_RZ = 0;
int rotate_command_Z = 0;
int z_height_command = 1;

const int SERIAL_BUFFER = 96;
char serial_buffer[SERIAL_BUFFER];
int serial_index = 0;

int tripod_case[6] = {1, 2, 1, 2, 1, 2};   // for tripod gait walking
int ripple_case[6] = {2, 6, 4, 1, 3, 5};   // for ripple gait
int wave_case[6] = {1, 2, 3, 4, 5, 6};     // for wave gait
int tetrapod_case[6] = {1, 3, 2, 1, 2, 3}; // for tetrapod gait

//***********************************************************************
// Object Declarations
//***********************************************************************
Servo coxa1_servo; // 18 servos
Servo femur1_servo;
Servo tibia1_servo;
Servo coxa2_servo;
Servo femur2_servo;
Servo tibia2_servo;
Servo coxa3_servo;
Servo femur3_servo;
Servo tibia3_servo;
Servo coxa4_servo;
Servo femur4_servo;
Servo tibia4_servo;
Servo coxa5_servo;
Servo femur5_servo;
Servo tibia5_servo;
Servo coxa6_servo;
Servo femur6_servo;
Servo tibia6_servo;

//***********************************************************************
// Function Prototypes
//***********************************************************************
void process_serial_commands();
void handle_serial_command(char *line);
void update_body_pose_offsets();

//***********************************************************************
// Initialization Routine
//***********************************************************************
void setup()
{
  // start serial
  Serial.begin(115200);
  Serial2.begin(9600);

  // attach servos
  coxa1_servo.attach(COXA1_SERVO, 610, 2400);
  femur1_servo.attach(FEMUR1_SERVO, 610, 2400);
  tibia1_servo.attach(TIBIA1_SERVO, 610, 2400);
  coxa2_servo.attach(COXA2_SERVO, 610, 2400);
  femur2_servo.attach(FEMUR2_SERVO, 610, 2400);
  tibia2_servo.attach(TIBIA2_SERVO, 610, 2400);
  coxa3_servo.attach(COXA3_SERVO, 610, 2400);
  femur3_servo.attach(FEMUR3_SERVO, 610, 2400);
  tibia3_servo.attach(TIBIA3_SERVO, 610, 2400);
  coxa4_servo.attach(COXA4_SERVO, 610, 2400);
  femur4_servo.attach(FEMUR4_SERVO, 610, 2400);
  tibia4_servo.attach(TIBIA4_SERVO, 610, 2400);
  coxa5_servo.attach(COXA5_SERVO, 610, 2400);
  femur5_servo.attach(FEMUR5_SERVO, 610, 2400);
  tibia5_servo.attach(TIBIA5_SERVO, 610, 2400);
  coxa6_servo.attach(COXA6_SERVO, 610, 2400);
  femur6_servo.attach(FEMUR6_SERVO, 610, 2400);
  tibia6_servo.attach(TIBIA6_SERVO, 610, 2400);

  // initialize manual leg defaults
  leg1_coxa = 90.0;
  leg1_femur = 90.0;
  leg1_tibia = 90.0;
  leg6_coxa = 90.0;
  leg6_femur = 90.0;
  leg6_tibia = 90.0;

  Serial.println("Hexapod listo. Escriba HELP para ver comandos seriales.");

  // clear offsets
  for (leg_num = 0; leg_num < 6; leg_num++)
  {
    offset_X[leg_num] = 0.0;
    offset_Y[leg_num] = 0.0;
    offset_Z[leg_num] = 0.0;
  }
  step_height_multiplier = 1.0;

  // initialize mode and gait variables
  mode = 0;
  gait = 2;
  gait_speed = 0;
  reset_position = true;
  leg1_IK_control = true;
  leg6_IK_control = true;
}

//***********************************************************************
// Main Program
//***********************************************************************
void loop()
{
  process_serial_commands();

  // set up frame time
  currentTime = millis();
  if ((currentTime - previousTime) > FRAME_TIME_MS)
  {
    previousTime = currentTime;

    // reset legs to home position when commanded
    if (reset_position == true)
    {
      for (leg_num = 0; leg_num < 6; leg_num++)
      {
        current_X[leg_num] = HOME_X[leg_num];
        current_Y[leg_num] = HOME_Y[leg_num];
        current_Z[leg_num] = HOME_Z[leg_num];
      }
      reset_position = false;
    }

    update_body_pose_offsets();

    // position legs using IK calculations - unless set all to 90 degrees mode
    if (mode < 99)
    {
      for (leg_num = 0; leg_num < 6; leg_num++)
        leg_IK(leg_num, current_X[leg_num] + offset_X[leg_num], current_Y[leg_num] + offset_Y[leg_num], current_Z[leg_num] + offset_Z[leg_num]);
    }

    // reset leg lift first pass flags if needed
    if (mode != 4)
    {
      leg1_IK_control = true;
      leg6_IK_control = true;
    }

    battery_monitor(); // battery monitor update
    // print_debug();     // print debug data

    // process modes (mode 0 is default 'home idle' do-nothing mode)
    if (mode == 1) // walking mode
    {
      if (gait == 0)
        tripod_gait(); // walk using gait 0
      if (gait == 1)
        wave_gait(); // walk using gait 1
      if (gait == 2)
        ripple_gait(); // walk using gait 2
      if (gait == 3)
        tetrapod_gait(); // walk using gait 3
    }
    if (mode == 4)
      one_leg_lift(); // one leg lift mode
    if (mode == 99)
      set_all_90(); // set all servos to 90 degrees mode
  }
}

//***********************************************************************
// Serial command handling
//***********************************************************************
void process_serial_commands()
{
  while (Serial2.available()>0) //>0
  {
    char incoming = Serial2.read();

    if (incoming == '\n' || incoming == '\r')
    {
      if (serial_index > 0)
      {
        serial_buffer[serial_index] = '\0';
        handle_serial_command(serial_buffer);
        serial_index = 0;
      }
    }
    else if (serial_index < (SERIAL_BUFFER - 1))
    {
      serial_buffer[serial_index++] = incoming;
    }
  }
}

void handle_serial_command(char *line)
{
  if (line[0] == '\0')
    return;

  for (int i = 0; line[i] != '\0'; i++)
    line[i] = toupper(line[i]);

  char *cmd = strtok(line, " ");
  if (cmd == NULL)
    return;

  if (strcmp(cmd, "HELP") == 0)
  {
    Serial.println("Comandos: MODE, GAIT, SPEED, WALK x y r, TRANS x y z, ROT rx ry rz z, STEPH n, LEG1 c f t, LEG6 c f t, RESET, SET90, BATT");
    return;
  }

  if (strcmp(cmd, "MODE") == 0)
  {
    char *arg = strtok(NULL, " ");
    if (arg != NULL)
    {
      int requested_mode = constrain(atoi(arg), 0, 99);
      if (requested_mode == 2 || requested_mode == 3)
        requested_mode = 1;
      mode = requested_mode;
      reset_position = true;
      if (mode != 4)
      {
        leg1_IK_control = true;
        leg6_IK_control = true;
      }
      else
      {
        leg1_IK_control = false;
        leg6_IK_control = false;
      }
    }
    return;
  }

  if (strcmp(cmd, "GAIT") == 0)
  {
    char *arg = strtok(NULL, " ");
    if (arg != NULL)
      gait = constrain(atoi(arg), 0, 3);
    return;
  }

  if (strcmp(cmd, "SPEED") == 0)
  {
    char *arg = strtok(NULL, " ");
    if (arg != NULL)
      gait_speed = (atoi(arg) != 0) ? 1 : 0;
    return;
  }

  if (strcmp(cmd, "WALK") == 0)
  {
    char *argX = strtok(NULL, " ");
    char *argY = strtok(NULL, " ");
    char *argR = strtok(NULL, " ");
    if (argX && argY && argR)
    {
      walk_command_X = constrain(atoi(argX), -127, 127);
      walk_command_Y = constrain(atoi(argY), -127, 127);
      walk_command_R = constrain(atoi(argR), -127, 127);
    }
    return;
  }

  if (strcmp(cmd, "TRANS") == 0)
  {
    char *argX = strtok(NULL, " ");
    char *argY = strtok(NULL, " ");
    char *argZ = strtok(NULL, " ");
    if (argX && argY && argZ)
    {
      translate_command_X = constrain(atoi(argX), -2 * TRAVEL, 2 * TRAVEL);
      translate_command_Y = constrain(atoi(argY), -2 * TRAVEL, 2 * TRAVEL);
      translate_command_Z = constrain(atoi(argZ), -3 * TRAVEL, TRAVEL);
    }
    return;
  }

  if (strcmp(cmd, "ROT") == 0)
  {
    char *argRX = strtok(NULL, " ");
    char *argRY = strtok(NULL, " ");
    char *argRZ = strtok(NULL, " ");
    char *argZ = strtok(NULL, " ");
    if (argRX && argRY && argRZ && argZ)
    {
      rotate_command_RX = constrain(atoi(argRX), -12, 12);
      rotate_command_RY = constrain(atoi(argRY), -12, 12);
      rotate_command_RZ = constrain(atoi(argRZ), -30, 30);
      rotate_command_Z = constrain(atoi(argZ), -3 * TRAVEL, TRAVEL);
    }
    return;
  }

  if (strcmp(cmd, "STEPH") == 0)
  {
    char *arg = strtok(NULL, " ");
    if (arg != NULL)
    {
      z_height_command = constrain(atoi(arg), 1, 8);
      step_height_multiplier = 1.0 + ((z_height_command - 1.0) / 3.0);
    }
    return;
  }

  if (strcmp(cmd, "BATT") == 0)
  {
    Serial.print("BATT ");
    Serial.print(voltage * 3, 2);
    Serial.println(" V");
    return;
  }

  if (strcmp(cmd, "LEG1") == 0)
  {
    char *argC = strtok(NULL, " ");
    char *argF = strtok(NULL, " ");
    char *argT = strtok(NULL, " ");
    if (argC && argF && argT)
    {
      leg1_coxa = constrain(atoi(argC), 45, 135);
      leg1_femur = constrain(atoi(argF), 0, 170);
      leg1_tibia = constrain(atoi(argT), 0, 170);
      leg1_IK_control = false;
    }
    return;
  }

  if (strcmp(cmd, "LEG6") == 0)
  {
    char *argC = strtok(NULL, " ");
    char *argF = strtok(NULL, " ");
    char *argT = strtok(NULL, " ");
    if (argC && argF && argT)
    {
      leg6_coxa = constrain(atoi(argC), 45, 135);
      leg6_femur = constrain(atoi(argF), 0, 170);
      leg6_tibia = constrain(atoi(argT), 0, 170);
      leg6_IK_control = false;
    }
    return;
  }

  if (strcmp(cmd, "RESET") == 0)
  {
    reset_position = true;
    return;
  }

  if (strcmp(cmd, "SET90") == 0)
  {
    mode = 99;
    return;
  }

  Serial.println("Comando desconocido");
}

// offsets are recalculated dynamically in update_body_pose_offsets()

//***********************************************************************
// Leg IK Routine
//***********************************************************************
void leg_IK(int leg_number, float X, float Y, float Z)
{
  // compute target femur-to-toe (L3) length
  L0 = sqrt(sq(X) + sq(Y)) - COXA_LENGTH;
  L3 = sqrt(sq(L0) + sq(Z));

  // process only if reach is within possible range (not too long or too short!)
  if ((L3 < (TIBIA_LENGTH + FEMUR_LENGTH)) && (L3 > (TIBIA_LENGTH - FEMUR_LENGTH)))
  {
    // compute tibia angle
    phi_tibia = acos((sq(FEMUR_LENGTH) + sq(TIBIA_LENGTH) - sq(L3)) / (2 * FEMUR_LENGTH * TIBIA_LENGTH));
    theta_tibia = phi_tibia * RAD_TO_DEG - 23.0 + TIBIA_CAL[leg_number];
    theta_tibia = constrain(theta_tibia, 0.0, 180.0);

    // compute femur angle
    gamma_femur = atan2(Z, L0);
    phi_femur = acos((sq(FEMUR_LENGTH) + sq(L3) - sq(TIBIA_LENGTH)) / (2 * FEMUR_LENGTH * L3));
    theta_femur = (phi_femur + gamma_femur) * RAD_TO_DEG + 14.0 + 90.0 + FEMUR_CAL[leg_number];
    theta_femur = constrain(theta_femur, 0.0, 180.0);

    // compute coxa angle
    theta_coxa = atan2(X, Y) * RAD_TO_DEG + COXA_CAL[leg_number];

    // output to the appropriate leg
    switch (leg_number)
    {
    case 0:
      if (leg1_IK_control == true) // flag for IK or manual control of leg
      {
        theta_coxa = theta_coxa + 45.0; // compensate for leg mounting
        theta_coxa = constrain(theta_coxa, 0.0, 180.0);
        coxa1_servo.write(int(theta_coxa));
        femur1_servo.write(int(theta_femur));
        tibia1_servo.write(int(theta_tibia));
      }
      break;
    case 1:
      theta_coxa = theta_coxa + 90.0; // compensate for leg mounting
      theta_coxa = constrain(theta_coxa, 0.0, 180.0);
      coxa2_servo.write(int(theta_coxa));
      femur2_servo.write(int(theta_femur));
      tibia2_servo.write(int(theta_tibia));
      break;
    case 2:
      theta_coxa = theta_coxa + 135.0; // compensate for leg mounting
      theta_coxa = constrain(theta_coxa, 0.0, 180.0);
      coxa3_servo.write(int(theta_coxa));
      femur3_servo.write(int(theta_femur));
      tibia3_servo.write(int(theta_tibia));
      break;
    case 3:
      if (theta_coxa < 0)                // compensate for leg mounting
        theta_coxa = theta_coxa + 225.0; // (need to use different
      else                               //  positive and negative offsets
        theta_coxa = theta_coxa - 135.0; //  due to atan2 results above!)
      theta_coxa = constrain(theta_coxa, 0.0, 180.0);
      coxa4_servo.write(int(theta_coxa));
      femur4_servo.write(int(theta_femur));
      tibia4_servo.write(int(theta_tibia));
      break;
    case 4:
      if (theta_coxa < 0)                // compensate for leg mounting
        theta_coxa = theta_coxa + 270.0; // (need to use different
      else                               //  positive and negative offsets
        theta_coxa = theta_coxa - 90.0;  //  due to atan2 results above!)
      theta_coxa = constrain(theta_coxa, 0.0, 180.0);
      coxa5_servo.write(int(theta_coxa));
      femur5_servo.write(int(theta_femur));
      tibia5_servo.write(int(theta_tibia));
      break;
    case 5:
      if (leg6_IK_control == true) // flag for IK or manual control of leg
      {
        if (theta_coxa < 0)                // compensate for leg mounting
          theta_coxa = theta_coxa + 315.0; // (need to use different
        else                               //  positive and negative offsets
          theta_coxa = theta_coxa - 45.0;  //  due to atan2 results above!)
        theta_coxa = constrain(theta_coxa, 0.0, 180.0);
        coxa6_servo.write(int(theta_coxa));
        femur6_servo.write(int(theta_femur));
        tibia6_servo.write(int(theta_tibia));
      }
      break;
    }
  }
}

//***********************************************************************
// Tripod Gait
// Group of 3 legs move forward while the other 3 legs provide support
//***********************************************************************
void tripod_gait()
{
  // read commanded values from controller
  commandedX = constrain(walk_command_X, -127, 127);
  commandedY = constrain(walk_command_Y, -127, 127);
  commandedR = constrain(walk_command_R, -127, 127);

  // if commands more than deadband then process
  if ((abs(commandedX) > 15) || (abs(commandedY) > 15) || (abs(commandedR) > 15) || (tick > 0))
  {
    compute_strides();
    numTicks = round(duration / FRAME_TIME_MS / 2.0); // total ticks divided into the two cases
    for (leg_num = 0; leg_num < 6; leg_num++)
    {
      compute_amplitudes();
      switch (tripod_case[leg_num])
      {
      case 1: // move foot forward (raise and lower)
        current_X[leg_num] = HOME_X[leg_num] - amplitudeX * cos(M_PI * tick / numTicks);
        current_Y[leg_num] = HOME_Y[leg_num] - amplitudeY * cos(M_PI * tick / numTicks);
        current_Z[leg_num] = HOME_Z[leg_num] + abs(amplitudeZ) * sin(M_PI * tick / numTicks);
        if (tick >= numTicks - 1)
          tripod_case[leg_num] = 2;
        break;
      case 2: // move foot back (on the ground)
        current_X[leg_num] = HOME_X[leg_num] + amplitudeX * cos(M_PI * tick / numTicks);
        current_Y[leg_num] = HOME_Y[leg_num] + amplitudeY * cos(M_PI * tick / numTicks);
        current_Z[leg_num] = HOME_Z[leg_num];
        if (tick >= numTicks - 1)
          tripod_case[leg_num] = 1;
        break;
      }
    }
    // increment tick
    if (tick < numTicks - 1)
      tick++;
    else
      tick = 0;
  }
}
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

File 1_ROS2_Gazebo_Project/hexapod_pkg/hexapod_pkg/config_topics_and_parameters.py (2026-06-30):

#!/usr/bin/env python3

import os
# =================   ======   =================
# ================= ROS DOMAIN =================
# =================   ======   =================
"""
It is essential that the ROS domain is the same for both the PC and the Raspberry Pi in order for communication between them.
You can arbitrarily choose the domain as long as you make sure that both the PC and the Raspberry Pi have the same one.
For simulations, the domain can be neglected since all topics are published from the PC.
"""

ROS_DOMAIN_ID = 42

# This function allows you to verify the current domain of each node when it is launched.
def check_domain_id(logger=None):
    env = os.getenv("ROS_DOMAIN_ID")
    msg = (
        f"ROS_DOMAIN_ID={env} (expected {ROS_DOMAIN_ID})"
        if env else
        f"ROS_DOMAIN_ID NOT set (recommended {ROS_DOMAIN_ID})"
    )
    if logger:
        logger.warning(msg)
    else:
        print(msg)

# =================         ======          =================
# ================= SENSORS LECTURES TOPICS =================
# =================         ======          =================
"""
The following topics are those used by the sensor reading nodes (both for the simulation and the real robot), 
each with the specific handle for the type of data it publishes.

Note that the topics for the real robot are repeated and differentiated in "phone" sensor and "no phone sensor", 
this is because it is possible to optionally use real sensors as breakouts or sensors from a phone via an external 
application (such as SensorServer), where the latter was the final implementation for this project.
"""

# Obstacles detection topics (for de real robot)
TOPIC_PI_IR1 = "/pi/sensor/IR_measure1"                     # Topic type: Bool
TOPIC_PI_IR2 = "/pi/sensor/IR_measure2"                     # Topic type: Bool
TOPIC_PI_ULTRASONIC = "/pi/sensor/ultrasonic_read"          # Topic type: Range

# Localization and states topics (in case you use external sensor) (for de real robot)
TOPIC_PI_CAMERA = "/pi/camera/image_raw"                    # Topic type: Image
TOPIC_PI_IMU_GIR_ACC = "/pi/sensor/imu_data"                # Topic type: Imu
TOPIC_PI_MAG = "/pi/sensor/mag"                             # Topic type: MagneticField
TOPIC_PI_GPS = "/pi/sensor/gps_fix"                         # Topic type: Float32  

# Phone Sensor Localizaction and states topics (in case you use App SensorServer or simular) (for de real robot)
TOPIC_PI_PHONE_CAMERA = "/pi/phone/camera/image_raw"        # Topic type: Image
TOPIC_PI_PHONE_IMU_GIR_ACC = "/pi/phone/sensor/imu_data"    # Topic type: Imu
TOPIC_PI_PHONE_MAG = "/pi/phone/sensor/mag"                 # Topic type: MagneticField
TOPIC_PI_PHONE_GPS = "/pi/phone/sensor/gps_fix"             # Topic type: NavSatFix
TOPIC_PI_PHONE_HEADING = "/pi/phone/sensor/heading"         # Topic type: Float32  (heading obtained directly from the phone's sensors)

# TOPICS Only from simulation (From Gazebo)
TOPIC_GZ_CAMERA = '/camera/image_raw'                       # Topic type: Image
TOPIC_GZ_IMU_GIR_ACC = "/gz/sensor/imu_data"                # Topic type: Imu
TOPIC_GZ_MAG = "/gz/sensor/mag"                             # Topic type: MagneticField
TOPIC_GZ_GPS = "/gz/sensor/gps_fix"                         # Topic type: NavSatFix
TOPIC_GZ_IR1 = "/gz/sensor/IR_measure1"                     # Topic type: Bool
TOPIC_GZ_IR2 = "/gz/sensor/IR_measure2"                     # Topic type: Bool
TOPIC_GZ_ULTRASONIC = "/gz/sensor/ultrasonic_read"          # Topic type: Range

# =================                                  ======                                  =================
# ================= TOPICS FOR SENSOR DATA PROCESSING AND EXECUTION OF HIGH-LEVEL ALGORITHMS =================
# =================                                  ======                                  =================
# Image Recognition 
"""
Occupancy matrix used by the image procedure nodes that returns an NxN matrix over the image frame and places 0 in places 
where there are no detections and 1 in grids that coincide with detection positions.
"""
TOPIC_OBSTACLE_OCCUPATION_GRID = "/obstacle/occupation_grid"    # Topic type: Int8MultiArray
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

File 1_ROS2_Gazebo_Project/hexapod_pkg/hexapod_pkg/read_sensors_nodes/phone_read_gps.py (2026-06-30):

#!/usr/bin/env python3
# phone_read_gps.py

import json
import sys
import threading
import time
import websocket

import rclpy
from rclpy.node import Node
from sensor_msgs.msg import NavSatFix, NavSatStatus
from rclpy.qos import QoSProfile, ReliabilityPolicy, HistoryPolicy, DurabilityPolicy
from hexapod_pkg import config_topics_and_parameters as cfg


# ================= CONFIG =================
PHONE_IP = cfg.PHONEIP
PORT = 8080
GPS_URL = f"ws://{PHONE_IP}:{PORT}/gps"
# =========================================


class PhoneGPSNode(Node):

    def __init__(self):
        super().__init__("phone_gps_node")

        cfg.check_domain_id(self.get_logger())

        # ===== QoS PARAMETERS  =====
        # GPS, low rate
        self.declare_parameter("qos_reliability", "reliable")
        self.declare_parameter("qos_history", "keep_last")
        self.declare_parameter("qos_depth", 5)
        self.declare_parameter("qos_durability", "volatile")

        qos = self.build_qos_from_params()

        self.pub = self.create_publisher(
            NavSatFix,
            cfg.TOPIC_PI_PHONE_GPS,
            qos
        )

        self.closed = False
        self.ws = None

        self.get_logger().info("Phone GPS NavSatFix node ready")

    # ===== QoS BUILDER (NUEVO) =====
    def build_qos_from_params(self):
        reliability = self.get_parameter("qos_reliability").value
        history = self.get_parameter("qos_history").value
        depth = self.get_parameter("qos_depth").value
        durability = self.get_parameter("qos_durability").value

        return QoSProfile(
            reliability=ReliabilityPolicy.RELIABLE
            if reliability.lower() == "reliable"
            else ReliabilityPolicy.BEST_EFFORT,
            history=HistoryPolicy.KEEP_ALL
            if history.lower() == "keep_all"
            else HistoryPolicy.KEEP_LAST,
            depth=depth,
            durability=DurabilityPolicy.TRANSIENT_LOCAL
            if durability.lower() == "transient_local"
            else DurabilityPolicy.VOLATILE,
        )

    # ---------- WebSocket callbacks ----------
    def on_message(self, ws, message):
        try:
            data = json.loads(message)

            lat = data.get("latitude")
            lon = data.get("longitude")
            accuracy = data.get("accuracy", -1.0)

            if lat is None or lon is None:
                return

            msg = NavSatFix()
            msg.header.stamp = self.get_clock().now().to_msg()
            msg.header.frame_id = "gps_link"

            msg.status.status = NavSatStatus.STATUS_FIX
            msg.status.service = NavSatStatus.SERVICE_GPS

            msg.latitude = float(lat)
            msg.longitude = float(lon)
            msg.altitude = data.get("altitude", 0.0)

            # accuracy → varianza (m²)
            if accuracy > 0:
                msg.position_covariance[0] = accuracy ** 2
                msg.position_covariance[4] = accuracy ** 2
                msg.position_covariance[8] = accuracy ** 2
                msg.position_covariance_type = NavSatFix.COVARIANCE_TYPE_DIAGONAL_KNOWN
            else:
                msg.position_covariance_type = NavSatFix.COVARIANCE_TYPE_UNKNOWN

            self.pub.publish(msg)

        except Exception as e:
            self.get_logger().warn(f"GPS parsing error: {e}")

    def on_error(self, ws, error):
        self.get_logger().error(f"WebSocket error: {error}")

    def on_close(self, ws, close_code, reason):
        self.closed = True
        self.get_logger().warn(f"GPS connection closed: {reason}")

    def on_open(self, ws):
        self.get_logger().info("GPS conected")
        threading.Thread(
            target=self.send_requests,
            args=(ws,),
            daemon=True
        ).start()

    # ---------- Request loop ----------
    def send_requests(self, ws):
        while not self.closed:
            try:
                ws.send("getLastKnownLocation")
                time.sleep(1.0)  # 1 Hz
            except Exception:
                break

    # ---------- Start websocket ----------
    def start(self):
        self.ws = websocket.WebSocketApp(
            GPS_URL,
            on_open=self.on_open,
            on_message=self.on_message,
            on_error=self.on_error,
            on_close=self.on_close
        )

        self.ws.run_forever()


def ros_spin(node):
    rclpy.spin(node)


def main():
    rclpy.init()
    node = PhoneGPSNode()

    # ROS spin on separate thread
    threading.Thread(
        target=ros_spin,
        args=(node,),
        daemon=True
    ).start()

    node.start()

    node.destroy_node()
    rclpy.shutdown()
    sys.exit(0)


if __name__ == "__main__":
    main()
